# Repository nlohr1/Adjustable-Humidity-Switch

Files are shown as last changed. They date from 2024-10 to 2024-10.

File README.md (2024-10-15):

### Adjustable-Humidity-Switch

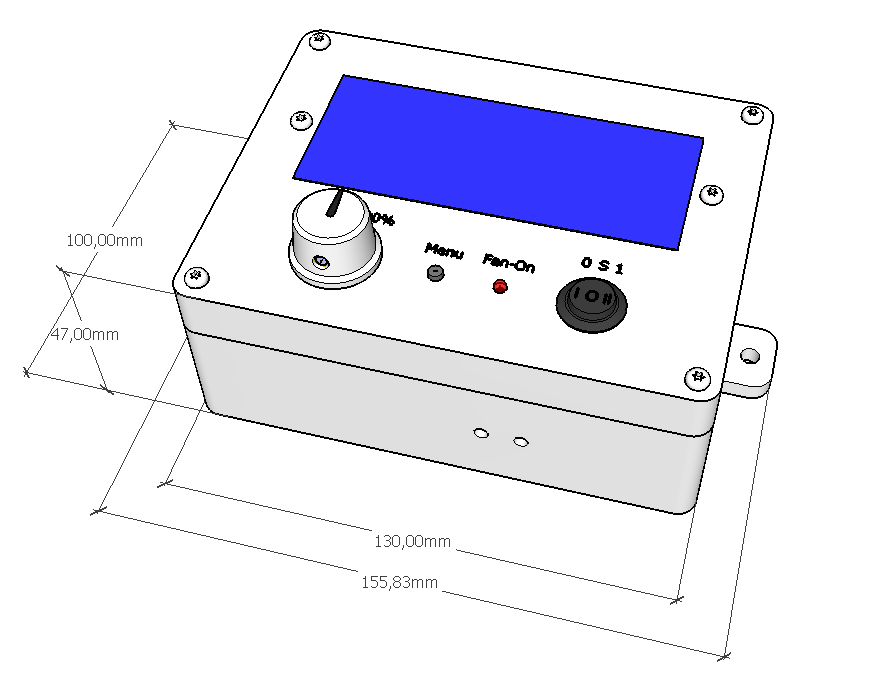
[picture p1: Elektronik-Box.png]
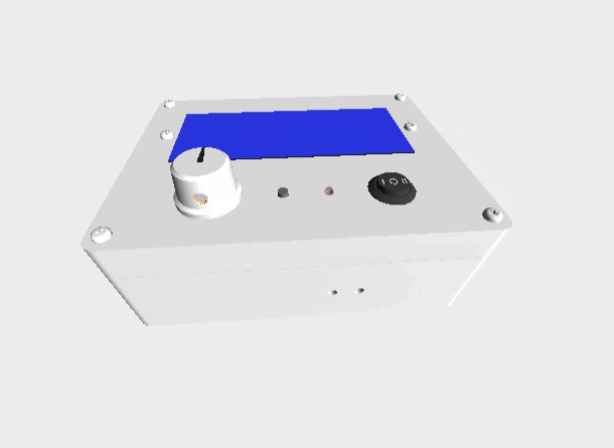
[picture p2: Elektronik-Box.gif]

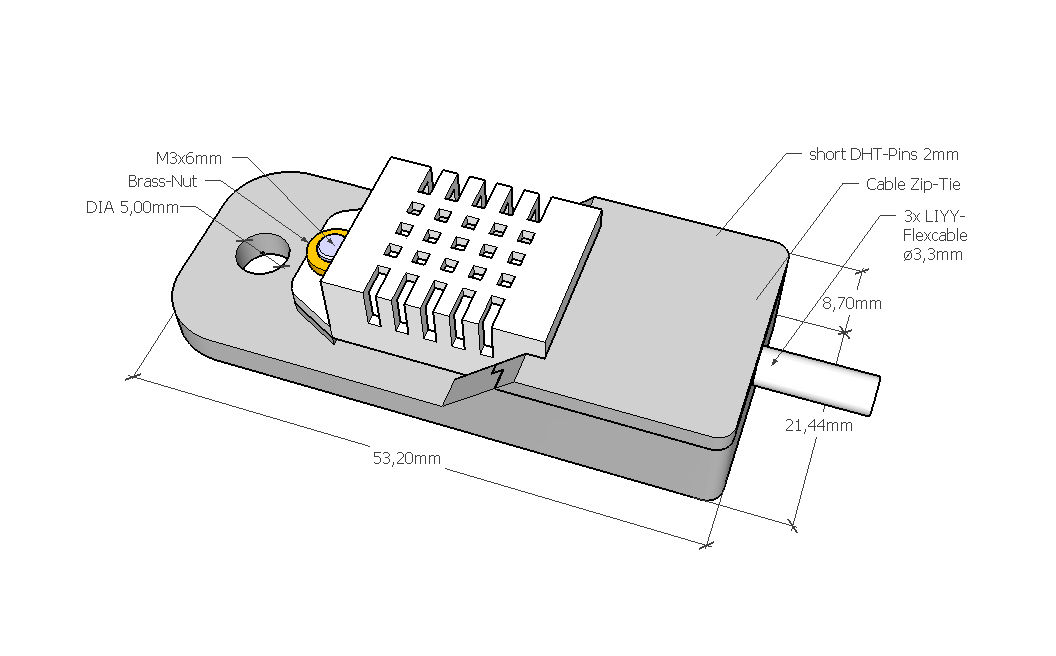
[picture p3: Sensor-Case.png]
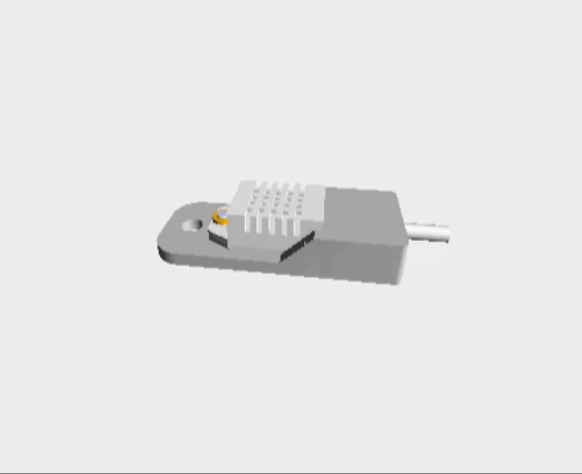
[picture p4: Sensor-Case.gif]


## EN: Adjustable Humidity-Switch
**Simple (de-)humidifier switch for all basements.**

Together with a dehumidifier or a mobile air conditioner, possibly with additional exhaust air, this is a way to keep out the poisonous "Aspergillus" (black or green mold) found in almost all basements, without using too much electricity. Unfortunately, with most dehumidifiers, the fan is always running - it cannot be switched off - and a ~800W to 3500W device can "eat up" a lot of electricity (150W continuous power for the fan?) - even if the compressor consumes most of it.  
What many people don't know or don't think about is that in many basements an invisible, radioactive gas diffuses out of the ground: radon. This gas is also odorless, so it is not noticeable, but acts like smoke - and in concentrations higher than the recommended limit (300 Bq/m³) it can attack the lungs in the long term... So if you are thinking of setting up a workspace or bedroom in the basement, you should also set up an appropriate extraction system.  
Another advantage of such an exhaust device compared to air conditioning systems or dehumidifiers: the moist, warm (+radon-containing) air is transported outside and the (indoor) air temperature remains almost the same without heating up (compressor waste heat).  
This switch works with a power relay, which can switch a consumer/device up to approx. 1400W on or off.  
The humidity threshold (the best for people is a relative humidity between 50-60%) - can be set with this switch. The dehumidifier is switched off with a small hysteresis (approx. -8% below the set value).  
I chose a capacitor type for the humidity sensor, the DHT22, because the DHT series is relatively stable and insensitive to environmental influences.  
I created and optimized the programming of the "Arduino Mini Pro" module, which handles the control and the LCD display, with the help of ChatGPT. This help makes troubleshooting in the program sequence much easier these days - so debugging is already extremely easyer.  
If you want to recreate the electronics required for this yourself, you can do it on a perforated board or recreate the board quite easily with the help of external service providers such as Eurocircuits or others. There are even (expensive) offers that take care of the assembly of the circuit board themselves. However, soldering in the few "THD" components should not be a problem for a DIY hobbyist.  

## DE: Einstellbarer Feuchte-Schalter
**Einfacher (Ent-)Feuchte Schalter für alle Keller.**

Zusammen mit einem Luftentfeuchter oder einem mobilen Klimagerät, evtl. mit zusätzlicher Abluft, ist dies eine Möglichkeit, den in fast allen Kellern anzutreffenden, giftigen "Aspergillus" (schwarzer oder grüner Schimmelbefall) fernzuhalten, ohne dabei allzu viel Strom zu verbrauchen. Bei den meisten Luftentfeuchtern läuft nämlich der Ventilator leider immer durch - nicht abschaltbar - und so ein ~800W bis 3500W Gerät kann tüchtig "Strom fressen" (150W Dauerleistung für den Lüfter?) - auch wenn der Kompressor das Meiste davon schluckt.  
Was viele zudem nicht wissen oder nicht daran denken - in vielen Kellern diffundiert ein unsichtbares, radioaktives Gas aus dem Boden: Radon. Dieses Gas ist zudem geruchlos, also nicht wahrnehmbar, wirkt aber wie Rauch - und kann in höherer Konzentration als dem empfohlenen Grenzwert (300 Bq/m³) längerfristig die Lunge angreifen... Falls man also gedenkt im Keller einen Arbeitsplatz oder ein Schlafzimmer einzurichten, sollte man dazu auch gleich eine entsprechende Absauganlage einrichten.  
Ein weiterer Vorteil eines solchen Abluft-Gerätes gegenüber Klimaanlagen oder Entfeuchtern: die feuchte, warme (+radonhaltige) Luft wird nach draußen befördert und die (Innen-)Lufttemperatur bleibt annähernd gleich, ohne sich zu erhitzen (Kompressor-Abwärme).  
Dieser Schalter arbeitet mit einem Power-Relais zusammen, welches einen Verbraucher/Gerät bis zu ca. 1400W ein- bzw. ausschalten kann.  
Die Feuchtigkeits-Schwelle (am besten für Menschen ist eine relative Luftfeuchtigkeit zwischen 50-60%) - ist bei diesem Schalter einstellbar. Mit einer kleinen Hysterese (ca. -8% unter dem eingestellten Wert) wird der Entfeuchter ausgestellt.  
Als Feuchtesensor habe ich einen Kondensator-Typ gewählt, den DHT22, da die DHT-Serie gegen Umwelteinflüsse relativ stabil und unempfindlich ist.  
Die Programmierung des "Arduino-Mini-Pro" Moduls, welches die Steuerung und die LCD-Anzeige übernimmt, habe ich mit Hilfe von ChatGPT erstellt und optimiert. Diese Hilfe vereinfacht heutzutage die Fehlersuche im Programmablauf - das "debugging" schon extrem.  
Wer die dazu erforderliche Elektronik selbst nachbauen will, kann diese auf einer Lochrasterplatine oder das Board mit Hilfe von externen Dienstleistern wie Eurocircuits o.a. auf recht einfache Weise nachbauen. Es gibt dazu sogar (teure) Angebote, die selbst die Bestückung der Leiterplatte übernhemen. Die wenigen "THD"-Bauteile einzulöten sollte aber kein Problem für einen DIY-Bastler sein.

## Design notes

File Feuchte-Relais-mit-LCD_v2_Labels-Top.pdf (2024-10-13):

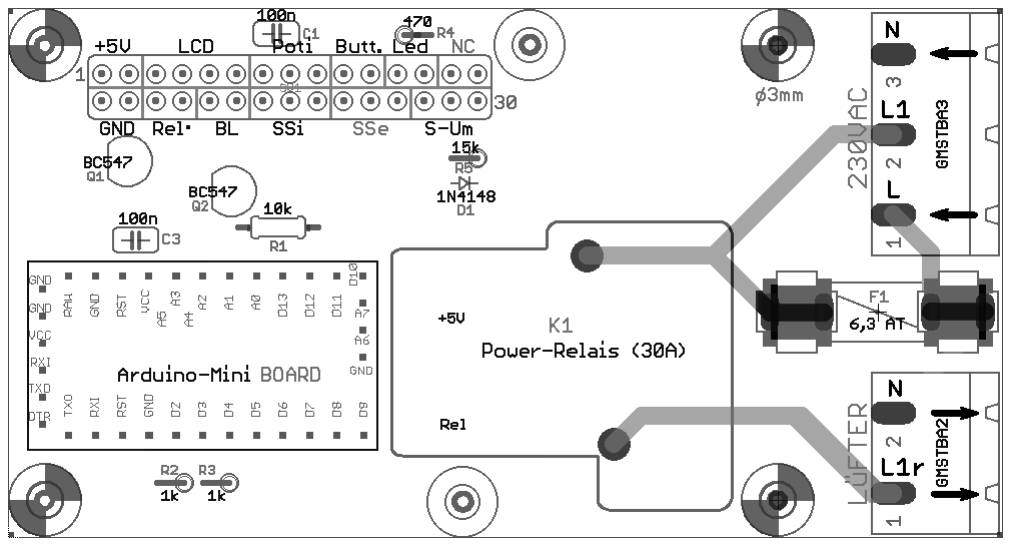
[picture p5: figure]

Feuchte-Relais-mit-RTC-&-LCD Top-Labels

Board: 94 x 50 mm

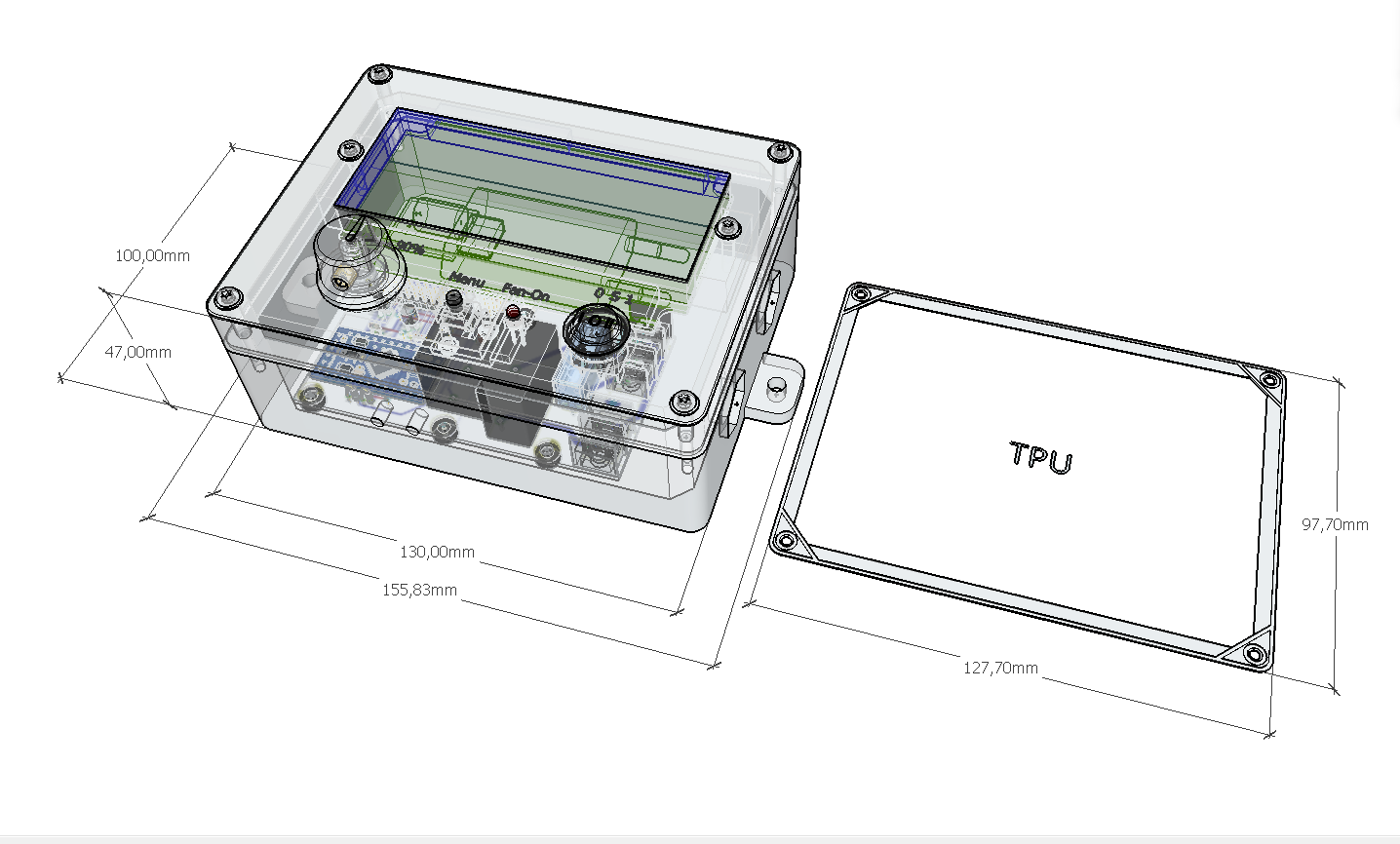
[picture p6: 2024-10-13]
Elektronik-Box-.png

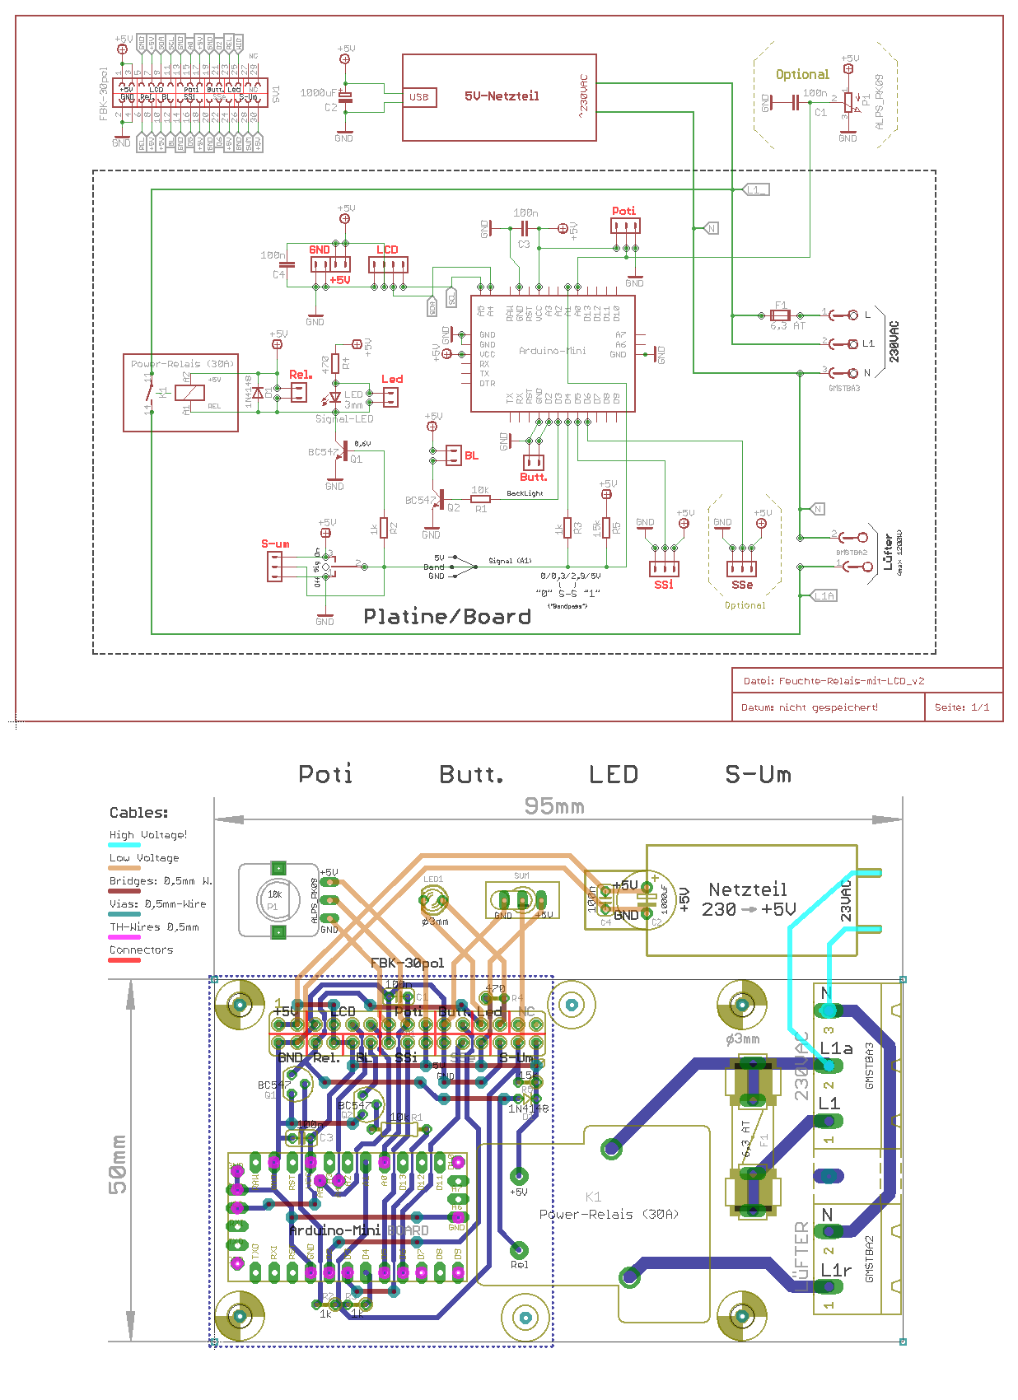
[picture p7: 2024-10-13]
Feuchte-Relais-mit-LCD_v2.png

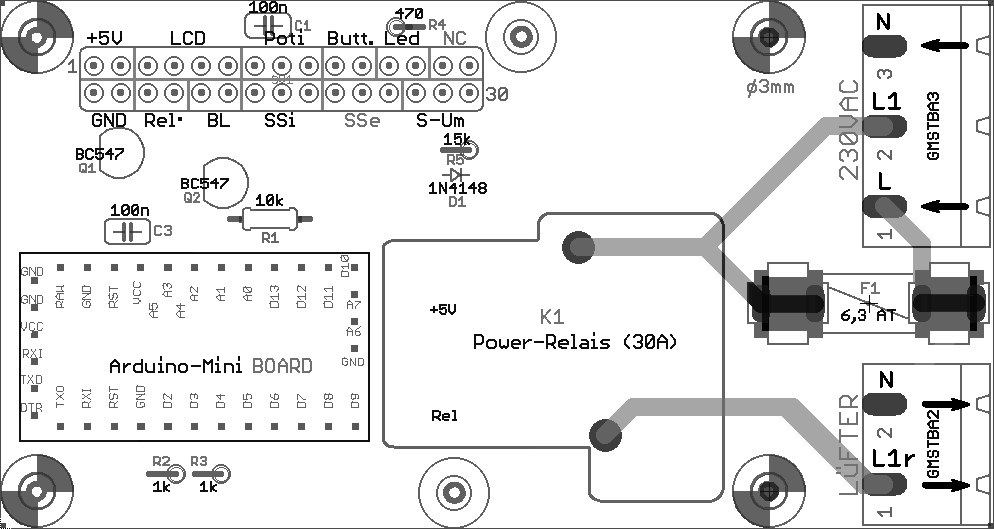
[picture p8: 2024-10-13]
Feuchte-Relais-mit-LCD_v2_Labels-Top.png

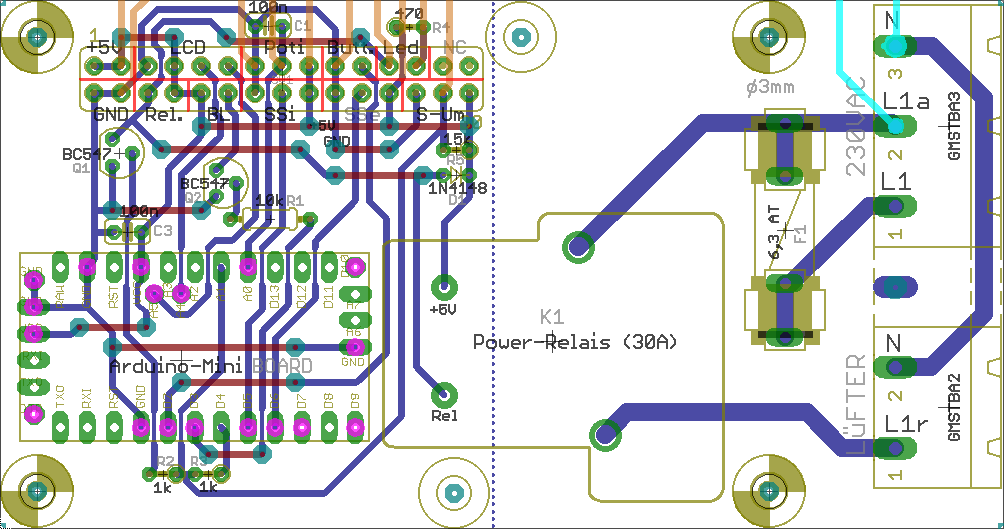
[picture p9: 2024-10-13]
Board_2D_Feuchte-Relais-mit-RTC-&-LCD.png

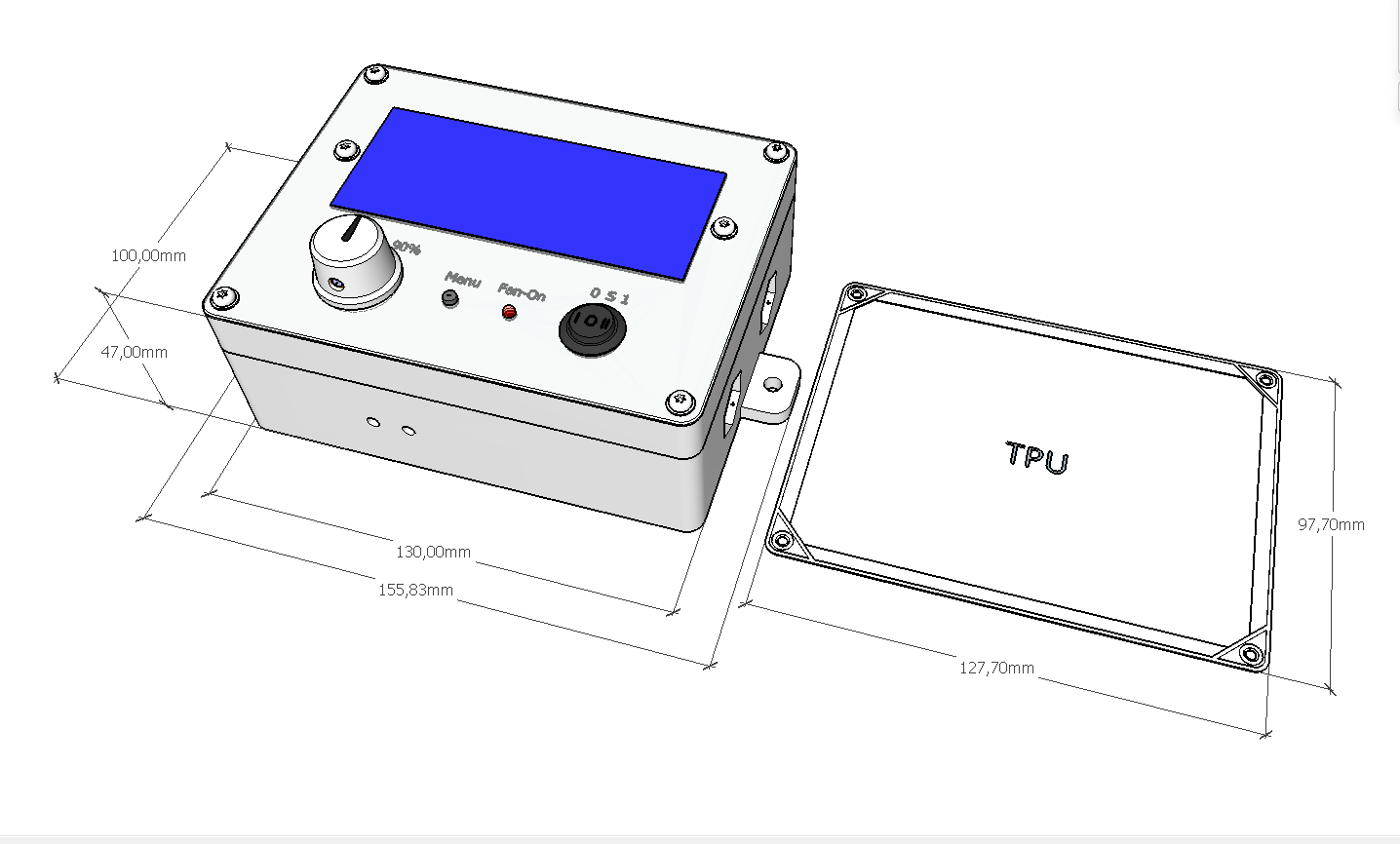
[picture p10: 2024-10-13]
Elektronik-Box+.png

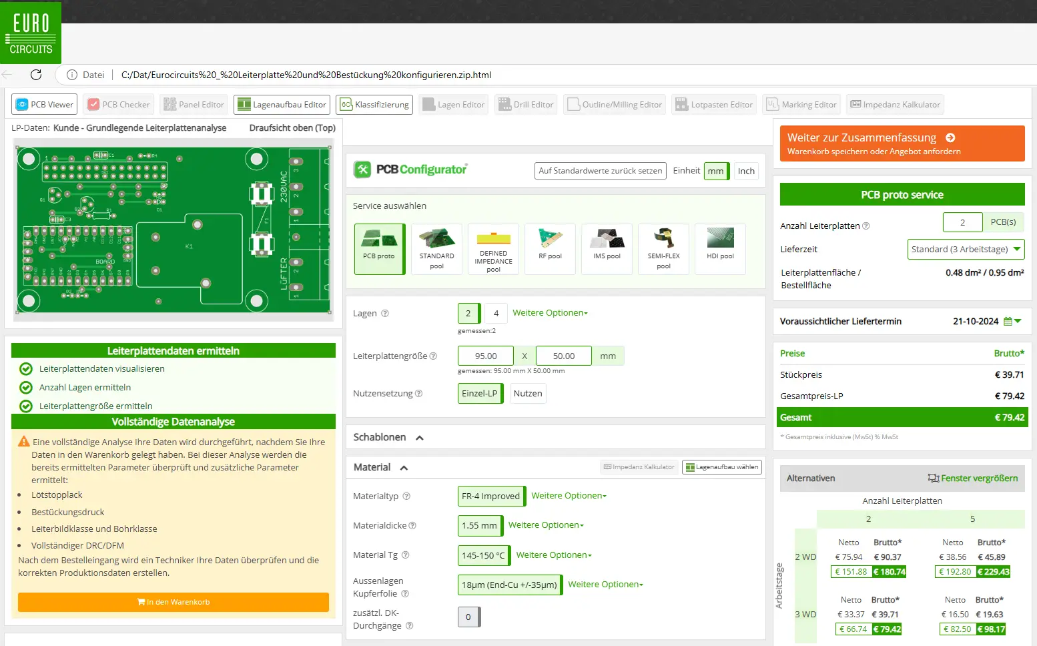
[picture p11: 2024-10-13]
Eurocircuits_Leiterplatten-Konfiguration_2x40,00 €.webp

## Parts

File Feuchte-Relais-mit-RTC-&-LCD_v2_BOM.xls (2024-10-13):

Manufacturer Part Number | Description | Reference Designator | Quantity | Manufacturer | Supplier Part Number | Supplier name | Package name | Mounting type | Comment | URL | URL-2
KF128 PCB Mount Terminal 7,5mm Pitch 3 Pin | PCB Screw Terminal, green, 6-Pin (3x2Pin) 7,62mm Pitch | 230VAC | 1 | --- | --- | --- | PCB board Connector | THD | (3Pin x2) | https://de.aliexpress.com/item/1005001677842589.html
Arduino-Mini-Pro, 5V | Arduino-Mini-Pro, 5V Module | BOARD | 1 | --- | --- | --- | ARDU-MINI | THD | Module | https://www.az-delivery.de/products/pro-mini-100-arduino-kompatibel
0.1uF 100V X7R Ceramic Capacitor, Radial, 2.54mm | Ceramic Capacitor, THD (2,54mm Pitch) | C1, C3, C4 | 3 | --- | --- | --- | C025-024 | THD | 100nF | https://de.aliexpress.com/item/1005005934204177.html | https://www.reichelt.de/vielschicht-kerko-100-nf-100-v-x7r-10-rm-2-5-ammo-x7r-2-5-100n-kom-p329838.html
470uF 60V Polarized Capacitor, Radial | Polarized Capacitor, THD (7,62mm Pitch) | C2 | 1 | --- | --- | --- | E3,5-8 | THD | 1000uF | https://www.reichelt.de/elko-radial-470-uf-35-v-105-c-low-esr-fm-a-470u-35-p200054.html
1N4148 | Generic Diode 100mA, THD (2,54mm Pitch) | D1 | 1 | --- | --- | --- | D-2.5 | THD | 1N4148 | https://www.reichelt.de/schalt-diode-100-v-150-ma-do-35-1n-4148-p1730.html
Fuse-Holder 6,3 AT | Fuse 5x20mm (for 1300W-Fan max.), THD | F1 | 1 | --- | --- | --- | FUSE | THD | Ø5xL:20mm | https://www.reichelt.de/feinsicherung-5x20mm-traege-6-3a-tr-6-3a-p21800.html | https://www.reichelt.de/sicherungshalter-fuer-5x20mm-6-3x32mm-pl-ogd-p53019.html
Power Relay 30A | Power Relay 230V, 30A, 5V (Schrack / Songle) | K1 | 1 | --- | --- | --- | ZD2 | THD | („Songle“-Relais) | https://de.aliexpress.com/item/1005006195915573.html | https://ampul.eu/de/relais-magnetische-kontakte/4824-relais-sla-05vdc-sl-c-5v-dc-250v-ac-30a
LED 3mm | LED diffuse red, THD | LED1 | 1 | --- | --- | --- | LED3MM | THD | 150mcd | https://www.reichelt.de/led-3mm-bedrahtet-rot-150-mcd-60--3004r1d-ehb-a-p361902.html
ALPS Rotary Potentiometer "RK09 Series" | Rotary Potentiometer | P1 | 1 | --- | --- | --- | RK09 | THD | 10k | https://in.rsdelivers.com/product/alps-alpine/rk097111030x/alps-alpine-10k%CF%89-rotary-carbon-film-potentiometer/2499121
Generic NPN-Transistor | BC547 NPN-Transistor | Q1, Q2 | 2 | --- | --- | --- | SOT54A | THD | (TO92) | https://www.ebay.de/itm/181079029042
Carbon Film Resistor (Yageo) | Resistor 0.25W, 5%, THD | R1 | 1 | --- | --- | --- | 0207 | THD | 10kΩ | https://www.reichelt.de/widerstand-kohleschicht-10-kohm-0207-250-mw-5--1-4w-10k-p1338.html
Carbon Film Resistor (Yageo) | Resistor 0.25W, 5%, THD | R2, R3 | 2 | --- | --- | --- | 0207 | THD | 1kΩ | https://www.reichelt.de/widerstand-kohleschicht-1-0-kohm-0207-250-mw-5--1-4w-1-0k-p1315.html
Carbon Film Resistor (Yageo) | Resistor 0.25W, 5%, THD | R4 | 1 | --- | --- | --- | 0207 | THD | 470 Ω | https://www.reichelt.de/widerstand-kohleschicht-470-ohm-0207-250-mw-5--1-4w-470-p1432.html
Carbon Film Resistor (Yageo) | Resistor 0.25W, 5%, THD | R5 | 1 | --- | --- | --- | 0207 | THD | 15kΩ | https://www.reichelt.de/widerstand-kohleschicht-15-kohm-0207-250-mw-5--1-4w-15k-p1356.html
Tiny Switch Rocker Black Round ON/OFF/ON 3 Pin | Switch On/Off/On | SUM | 1 | --- | --- | --- | TL3XPO | THD | On/Off/on | https://www.ebay.de/itm/184249111151
Dual Pin-Header 2.54mm, THD | Dual Pin-Header gold-plated 2.54mm, THD | SV1 | 1 | --- | --- | --- | MA15-2 | THD | Header / Crimp-Conn. | https://www.amazon.de/gp/product/B09NKXY4C4 | https://de.aliexpress.com/item/1005005670566115.html, https://www.ebay.de/itm/170938740983

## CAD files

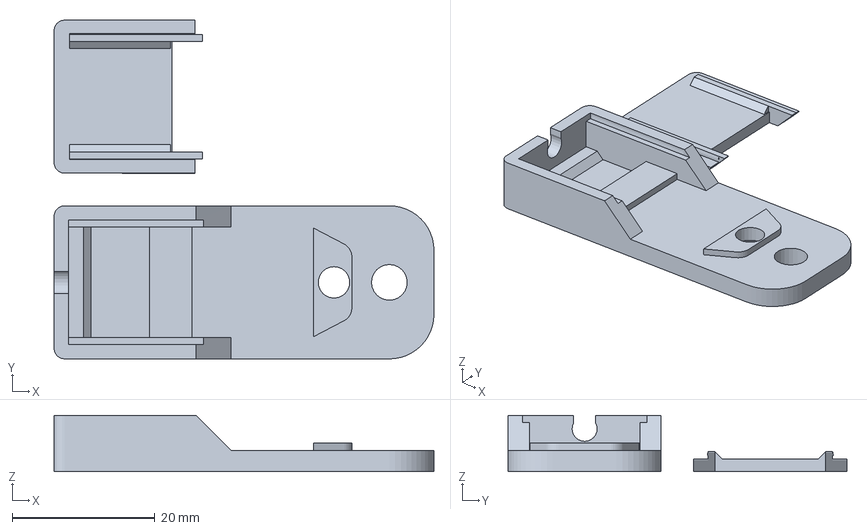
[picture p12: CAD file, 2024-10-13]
Sensor-Case/H-Sensor-Wallmount-Case.3mf
53.2 x 47.4 x 7.90 mm

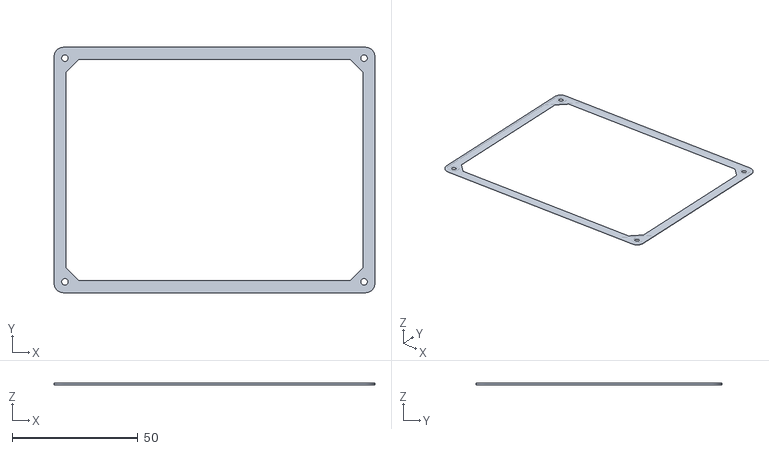
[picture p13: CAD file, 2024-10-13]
STL-Parts/Elektronik-Box_TPU_Seal.stl
127.7 x 97.7 x 0.6

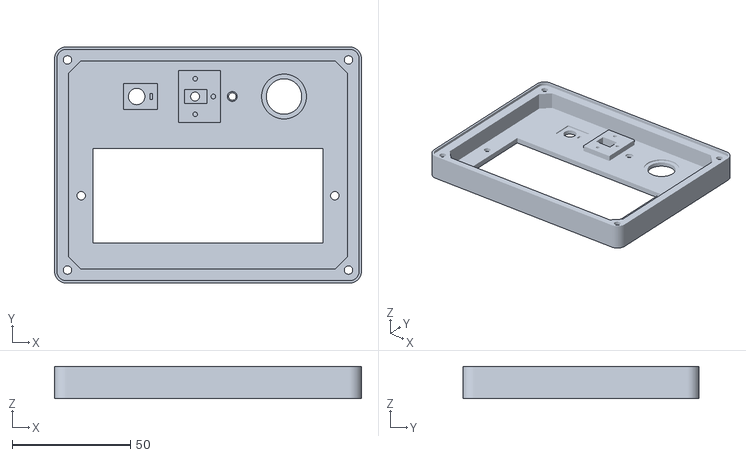
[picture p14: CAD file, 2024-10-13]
STL-Parts/Elektronik-Box_top.stl
130.0 x 100.0 x 13.6

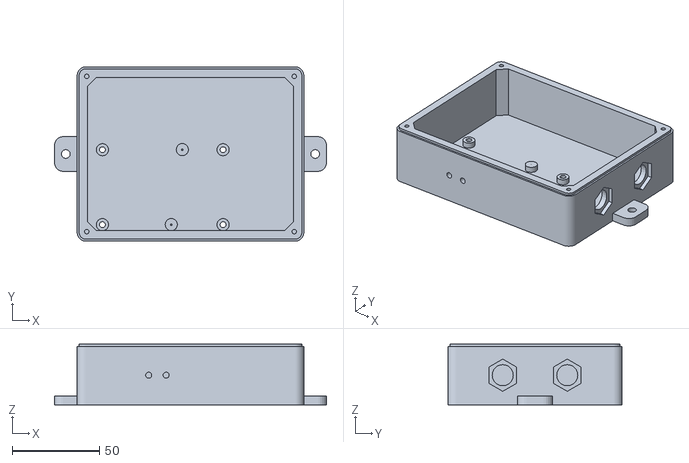
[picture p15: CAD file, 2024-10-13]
STL-Parts/Elektronik-Box_base_w-holes.stl
156.0 x 100.0 x 34.8

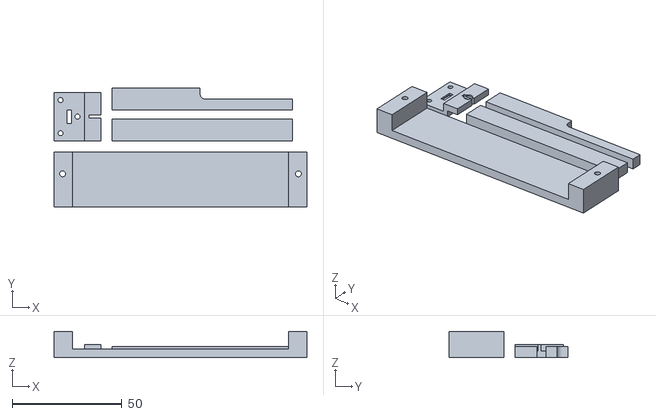
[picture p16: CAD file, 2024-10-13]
STL-Parts/LCD-Spacer_82x10x5mm.stl
115.2 x 54.0 x 12.0

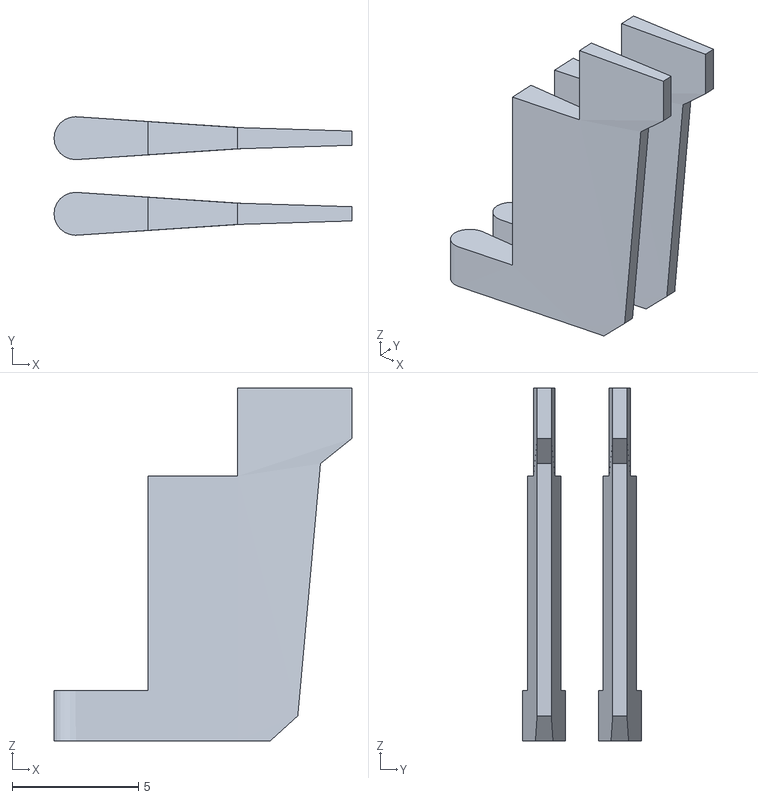
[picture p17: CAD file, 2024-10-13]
STL-Parts/Knob-Pointer_black.stl
11.8 x 4.70 x 14.0

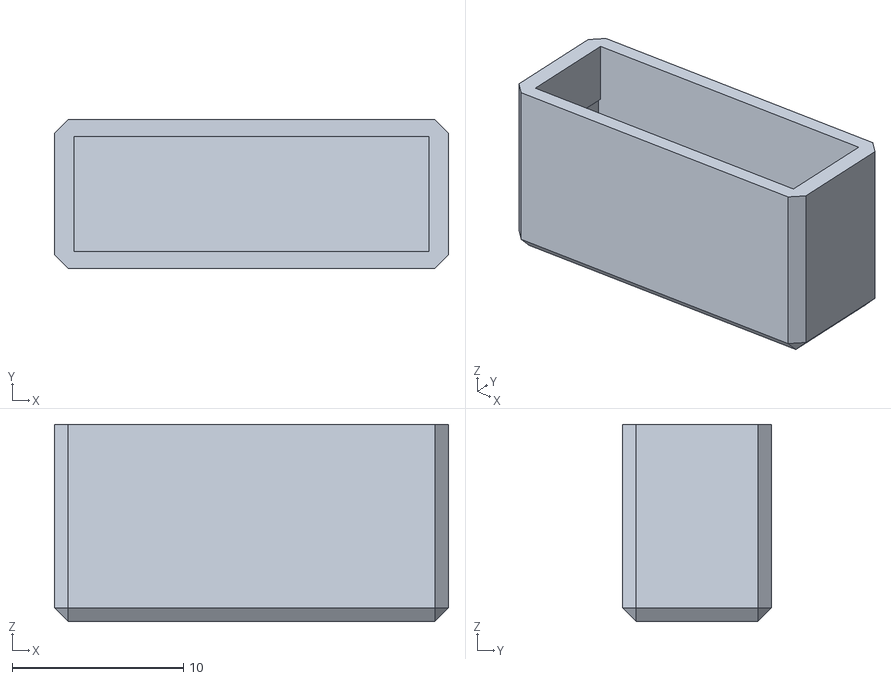
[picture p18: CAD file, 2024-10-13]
STL-Parts/Fuse cover.stl
23.0 x 8.70 x 11.5

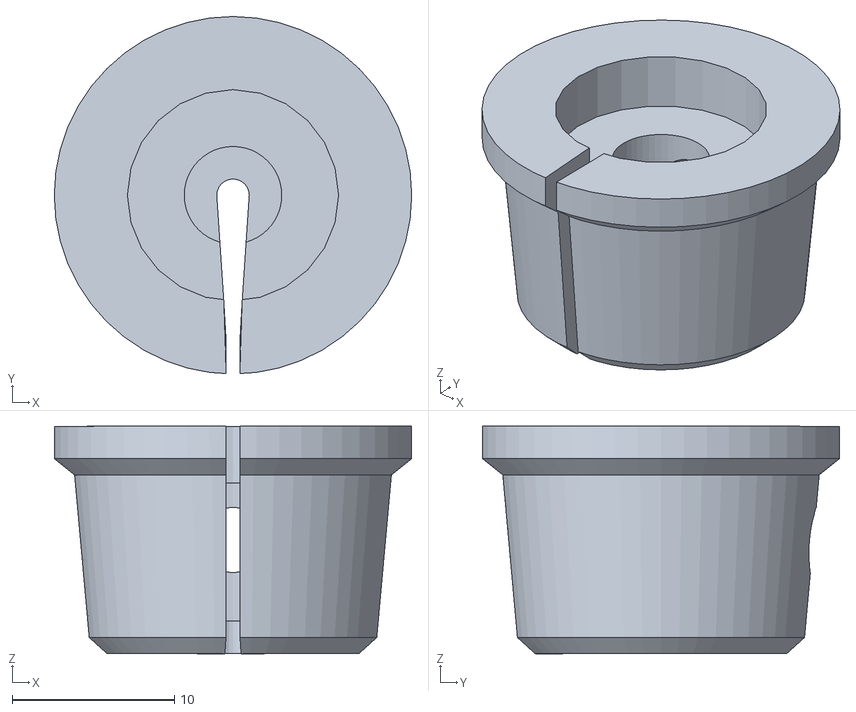
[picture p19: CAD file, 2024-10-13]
STL-Parts/Knob-white.stl
22.0 x 22.0 x 14.0

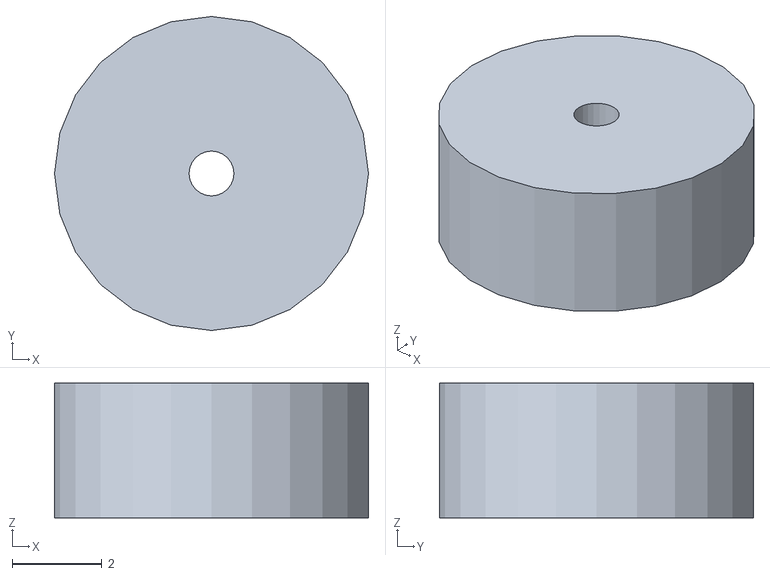
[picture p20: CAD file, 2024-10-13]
STL-Parts/Board-Spacer).stl
7.00 x 7.00 x 3.00

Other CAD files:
STL-Parts/Elektronik-Box_base_w-inserts.stl
Board-3D_Feuchte-Relais-mit-RTC-&-LCD.skp
Sensor-Case/H-Sensor-Wallmount-Case.skp
Sensor-Case/H-Sensor-Wallmount-Case.stl
Sensor-Case/Thread-Insert_M3-Brass.skp

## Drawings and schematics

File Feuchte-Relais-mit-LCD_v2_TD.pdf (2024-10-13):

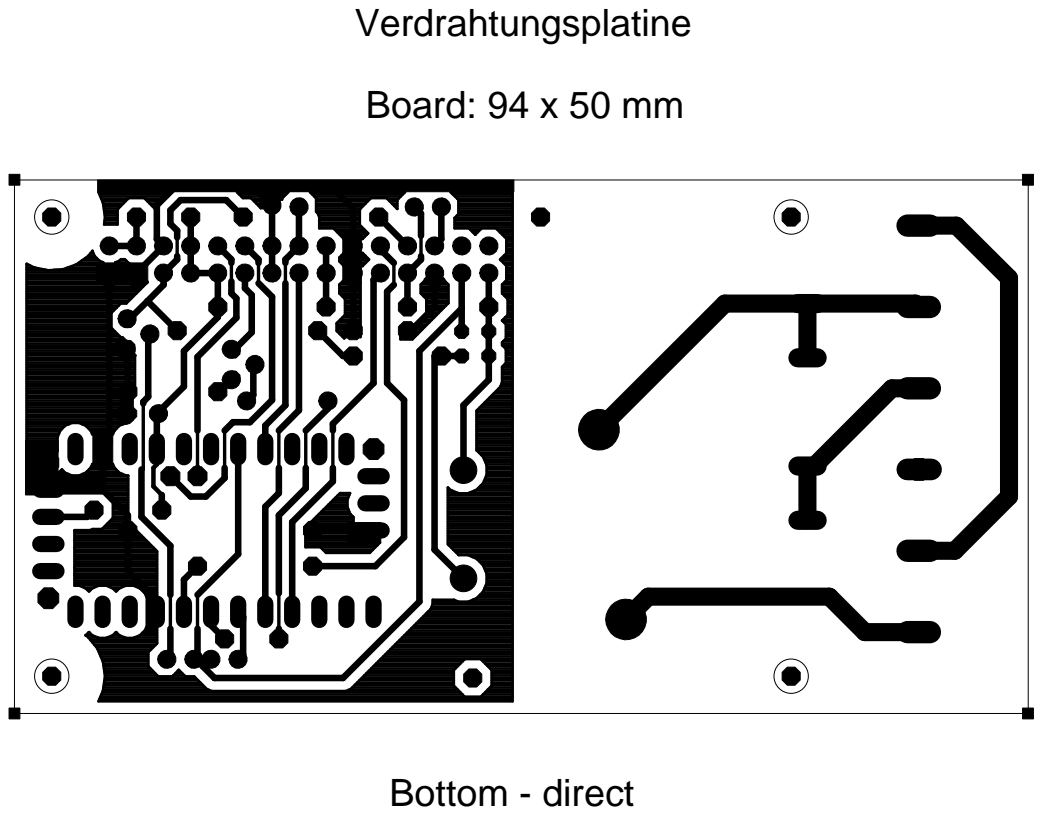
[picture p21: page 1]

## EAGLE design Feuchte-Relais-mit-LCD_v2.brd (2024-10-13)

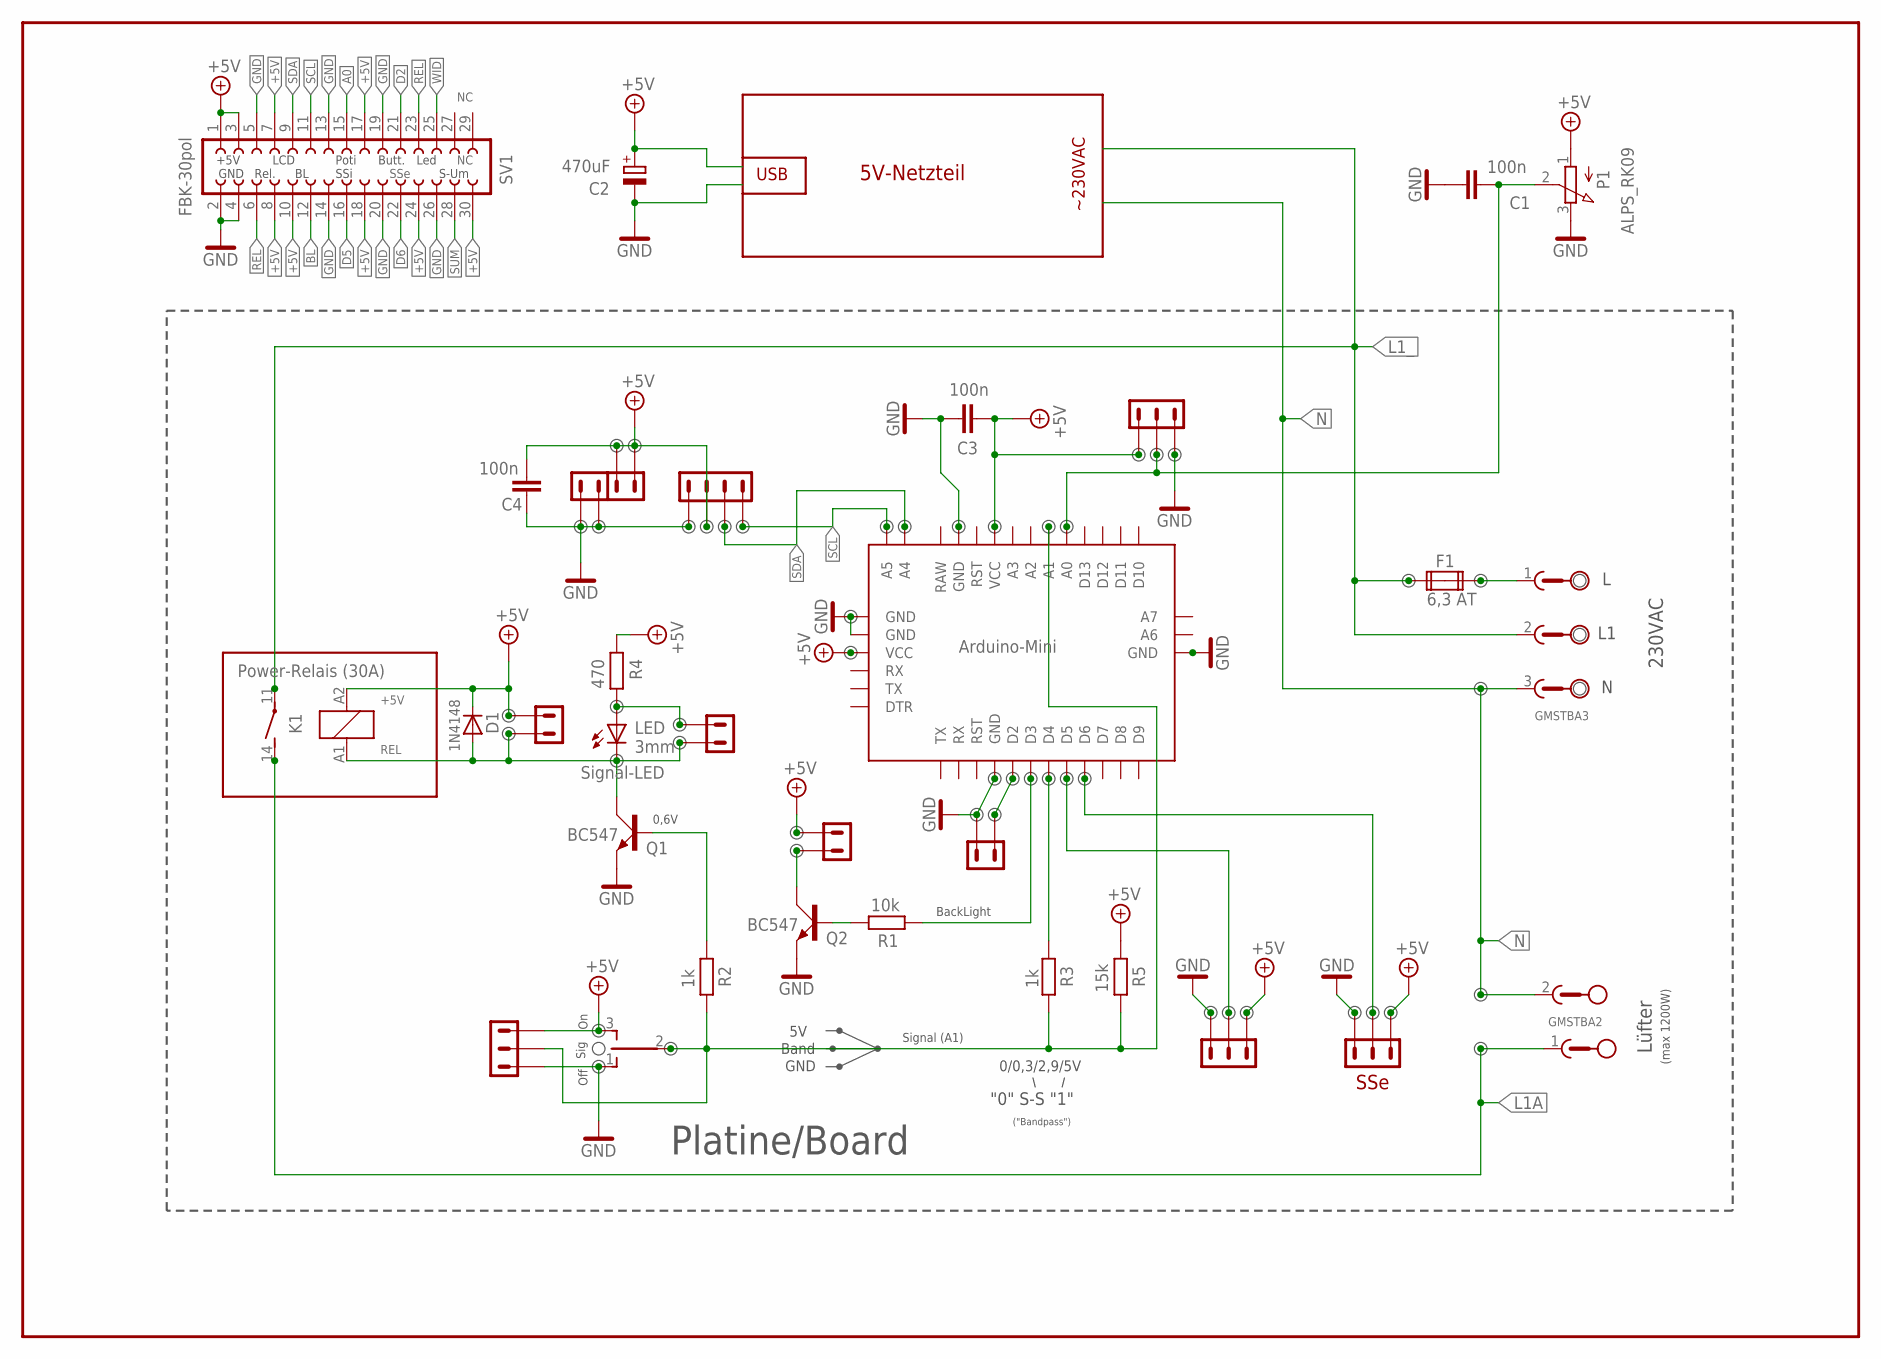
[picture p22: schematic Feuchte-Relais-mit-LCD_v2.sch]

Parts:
230VAC: GMSTBA3
BOARD: Arduino-Mini; ARDU-MINI
C1, C3, C4: 100n; C025-024X044
C2: 470uF; E3,5-8
D1: 1N4148; D-2.5
F1: 6,3 AT; FUSE1
K1: Power-Relais (30A); ZD2
LED1: o3mm; LED3MM
LüFTER: GMSTBA2
P1: ALPS_RK09; RK09
Q1, Q2: BC547; SOT54A
R1: 10k; 0204/7
R2, R3: 1k; 0204V
R4: 470; 0204V
R5: 15k; 0204V
SUM: TL39PO; TL3XPO
SV1: FBK-30pol; FE15-2

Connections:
+5V: BOARD.P$21 (VCC), BOARD.P$27 (VCC), C2.+, C3.1, C4.2, D1.C, K1.A2 (2), P1.1 (A), R4.1, R5.1, SUM.3 (S), SV1.1, SV1.3, SV1.7, SV1.8, SV1.10, SV1.17, SV1.18, SV1.24, SV1.30
A0: BOARD.P$17 (A0), C1.2, P1.2 (S), SV1.15
A1: BOARD.P$18 (A1), R2.1, R3.2, R5.2, SUM.2
BL: Q2.C, SV1.12
D2: BOARD.P$5 (D2), SV1.21
D3: BOARD.P$6 (D3), R1.1
D4: BOARD.P$7 (D4), R3.1
D5: BOARD.P$8 (D5), SV1.16
D6: BOARD.P$9 (D6), SV1.22
GND: BOARD.P$4 (GND), BOARD.P$23 (GND), BOARD.P$25 (GND), BOARD.P$26 (GND), BOARD.P$31 (GND), C1.1, C2.-, C3.2, C4.1, P1.3 (E), Q1.E, Q2.E, SUM.1 (O), SV1.2, SV1.4, SV1.5, SV1.13, SV1.14, SV1.19, SV1.20, SV1.26
L: 230VAC.1, F1.2A
L1A: K1.14 (S), LüFTER.1
L1_: 230VAC.2, F1.1A, K1.11
N: 230VAC.3, LüFTER.2
unnamed: Q1.B, R2.2
unnamed: Q2.B, R1.2
REL: D1.A, K1.A1 (1), LED1.K (C), Q1.C, SV1.6, SV1.23
SCL: BOARD.P$35 (A5), SV1.11
SDA: BOARD.P$34 (A4), SV1.9
SUM: SV1.28
WID: LED1.A, R4.2, SV1.25

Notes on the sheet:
USB
~230VAC
5V-Netzteil
Lüfter
Platine/Board
Off
Sig
Signal (A1)
230VAC
LED 3mm
BackLight
REL
+5V
(max 1200W)
Signal-LED
0/0,3/2,9/5V
"0" S-S "1"
("Bandpass")
0,6V
5V Band GND
GND
Rel.
LCD
S-Um
Butt.
Led
SSi
SSe
Poti

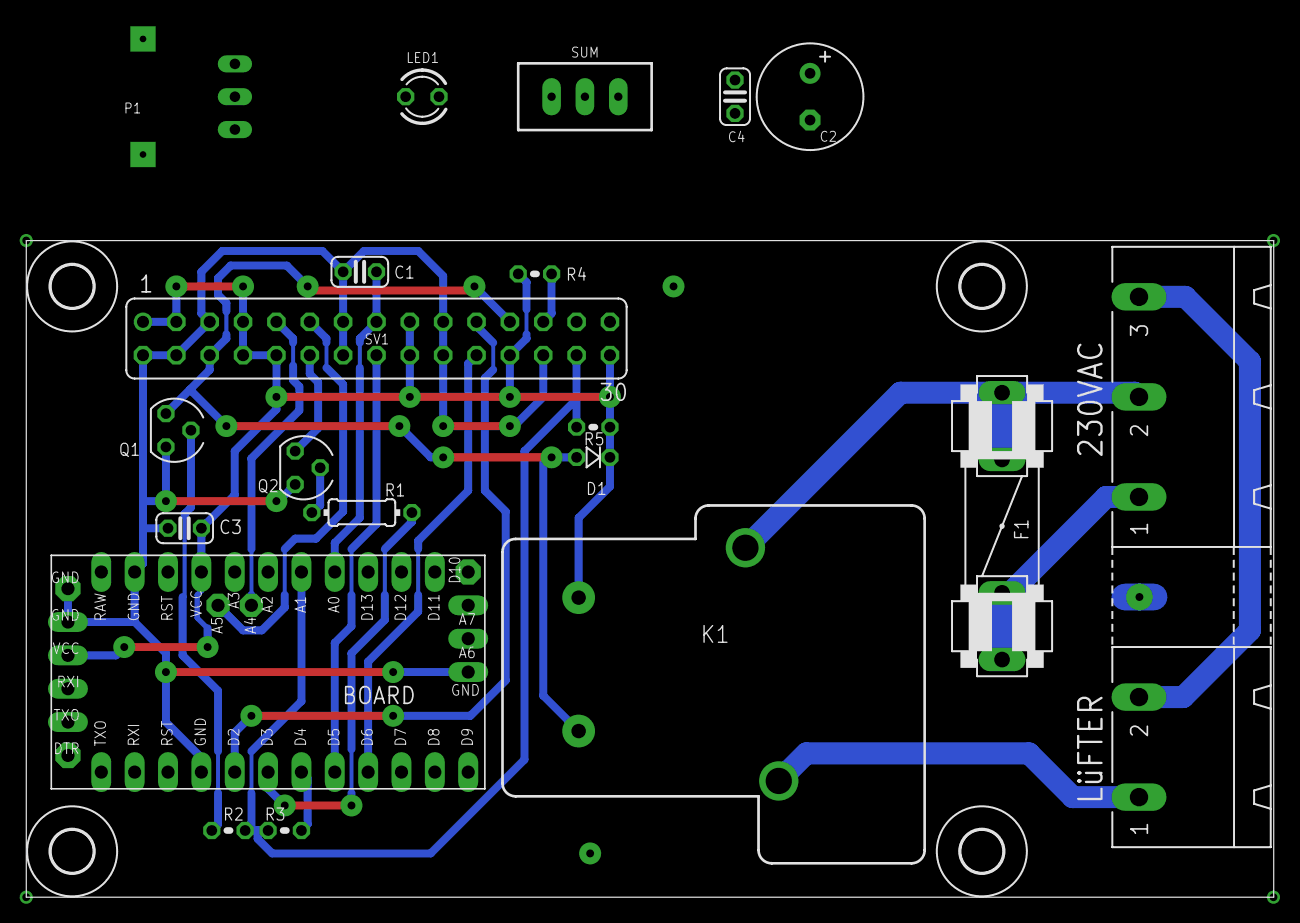
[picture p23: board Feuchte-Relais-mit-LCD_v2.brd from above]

Board: 2 copper layers, 95.0 x 50.0 mm, 25 parts (1 on the bottom side), 20 nets.

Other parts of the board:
U$1, U$2, U$3, U$4: 3,2

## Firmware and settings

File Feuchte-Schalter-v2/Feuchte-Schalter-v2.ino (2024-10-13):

//********************************************************************************
//Humidity-Relais with LCD-Display (20x4)
//********************************************************************************
//... (alle Kommentare und die ursprünglichen Komponentenbeschreibung) ...

//Libraries used:
#include "DHT.h"                 //https://github.com/adafruit/DHT-sensor-library
#include <SPI.h>                 //	(Arduino-internal) ../Arduino/hardware/arduino/avr/libraries/SPI
#include <Wire.h>                //(Arduino-internal) ../Arduino/libraries/Wire
#include <LiquidCrystal_I2C.h>   //https://github.com/fdebrabander/Arduino-LiquidCrystal-I2C-library

//Pin-Connections:
//Pin-Name          Pin //Explanation
#define potiPin     A0  //Input for the 10k-Poti
#define switchPin   A1  //Input for the 3-state Switch (0V | bandpass | 5V)
#define MenuPin     2   //Input for the Menu-Button (Att.: With internal PullUp-Resistor activated, see Setup)
#define pwmPinForBL 3   //PWM Output to turn-On the Backlight-Transistor (dimming with 2s transition)
#define RelaisPin   4   //Output Pin for the Relay Transistor
#define DHTPin_a    5   //Sensor_a Input (default configuration!)
#define DHTPin_b    6   //Sensor_b Input (only if 2nd. Dew Point Sensor present for automatic difference-calculation)

#define DHTType DHT22
DHT dht(DHTPin_a, DHTType);

//-------------------------- Variables ---------------------------
bool relais = false;            //Relay status
int potiValue = 0;              //Potentiometer value
int potiValueOld = 0;           //Previous potentiometer value
volatile bool BUTTON_2 = true;  //Button status for D2
float temperature;                     //Measured temperature
float humidity;                 //Measured humidity
unsigned long previous;         //Timestamp for display refresh
int hysterese = 6;              //Hysteresis for relay control
char tempStr[6];                //String buffer for temperature
char humidityStr[6];            //String buffer for humidity

bool backlightOn = false;       //Backlight status (if dimmed or full brightness)
unsigned long backlightPrevious = 0;   //Timestamp for backlight control
unsigned int backlightTimeout = 60000; //60 seconds timeout for backlight, then 1s dimming to 10% intensity
unsigned int displayRefreshInterval = 1500; //1.5 seconds interval = display refresh time
bool isDimming = false;         //Define a flag to prevent double dimming while dimming

LiquidCrystal_I2C lcd(0x27, 20, 4); //LCD: Address 0x27, 20 characters, 4 lines


//~~~~~~~~~~~~~~~~~~~~~~~~~~ Setup ~~~~~~~~~~~~~~~~~~~~~~~~~~
void setup() {
  Serial.begin(9600);
  dht.begin();  //initialize Humidity-Sensor

//Att.: On begin all Pins are Input-Pins, so no need to declare Input-Pins here twice - if used as Input...
  pinMode(RelaisPin, OUTPUT);
  pinMode(MenuPin, INPUT_PULLUP);  //Pullup activated for MenuPin (D2)

  attachInterrupt(digitalPinToInterrupt(MenuPin), ButtonD2_LOW, FALLING); 

  lcd.begin();        //initialize LCD-Display
  lcd.backlight();    //Backlight "On"
  dimBacklight(true); //Start with full backlight (100%), see dim-function @ the end

  byte Grad[8] = {B00111, B00101, B00111, B0000, B00000, B00000, B00000, B00000}; //Create custom character "°" as array
  lcd.createChar(0, Grad); //Create special character °, to display temperature in Centigrade on the LCD

}

//~~~~~~~~~~~~~~~~~~~~~~~~~~ Main-Loop ~~~~~~~~~~~~~~~~~~~~~~~~~~
void loop() {
  temperature = dht.readTemperature();
  humidity = dht.readHumidity();

  //Detection, if the Sensor sends a valid Signal:
  if (isnan(temperature) || isnan(humidity)) {
    lcd.clear();
    lcd.setCursor(0, 0);
    lcd.print("Sensor Error!");
    lcd.setCursor(0, 1);
    lcd.print("No values.");
    delay(2000);
    return;
  }

  //ReadOut of Poti-position:
  potiValue = analogRead(potiPin); //readout actual Poti-position
  potiValue = map(potiValue, 0, 1023, 20, 100); //calculate the spread (target is from 0-255)
  if (potiValue <= 30) { potiValue = 30; } //don't decrease below 30%
  if (potiValue >= 90) { potiValue = 90; } //don't increase above 90%

  //Activate the Relay if RH is just above potiValue - and deactivate if 8% below
  if (humidity >= potiValue) {
    digitalWrite(RelaisPin, HIGH);
    relais = true; //turn on the Relay
  } else if (humidity < potiValue - hysterese) {
    digitalWrite(RelaisPin, LOW);
    relais = false; //turn off the Relay
  }

  //if either the Poti or the MenuButton was touched...
  if ((BUTTON_2 == LOW || potiValue != potiValueOld) && !isDimming) { //"isDimming" = ensure only one dimming event
    dimBacklight(true); //...then set the backlight to 100% brightness
    backlightOn = true;
    backlightPrevious = millis(); //set value to actual millis()
    BUTTON_2 = HIGH;              //reset the flag
    potiValueOld = potiValue;
    isDimming = true;             // Set dimming flag to true
  }

  //TimeOut after 60 seconds:
  if (backlightOn && millis() - backlightPrevious >= backlightTimeout) {
    dimBacklight(false); //dim backlight to 10% brightness
    backlightOn = false;
    isDimming = false;            // Reset dimming flag after timeout
  }

  //Dimming-Timeout:
  if (millis() - previous >= displayRefreshInterval) { //1500ms
    previous = millis();

    dtostrf(temperature, 2, 0, tempStr);
    dtostrf(humidity, 2, 0, humidityStr);

    lcd.clear();              
    lcd.setCursor(0, 0);
    lcd.print("Temp.:   ");
    lcd.print(tempStr);
    lcd.write((uint8_t)0);  //° symbol
    lcd.print("C");

    lcd.setCursor(0, 1);      
    lcd.print("Feuchte: ");
    lcd.print(humidityStr);
    lcd.print(" %");

    lcd.setCursor(0, 2);      
    lcd.print("Poti:    ");
    lcd.print(potiValue);
    lcd.print(" %");

    lcd.setCursor(0, 3);      
    lcd.print("Trockner ");
    lcd.print(relais ? "EIN" : "AUS");
  }

  //Read analog value from Pin-A1 Input for switch status and display the result on LCD-Display (right side of the last line):
  int analogValue = analogRead(switchPin); //read-out the Switch-Position on Pin-A1 (input)
  lcd.setCursor(17, 3); //Move to the right side of the last line, position 17 (of 20)
    
  if (analogValue > 900) {
    lcd.print("__1"); //Permanent-On (Switch on +5V)
  }
  else if (analogValue > 60 && analogValue <= 900) {
    lcd.print("_S_"); //Sensor mode (Switch on "S" position ⇒ detect if within "bandpass" between 2.9V and 0.3V through analog-Pin A1)
  }
  else {
    lcd.print("0__"); //Permanent-Off (Switch on 0V)
  }

} //~~~~~~~~~~~~~~~~~~~~~~~~~~ End of Main-Loop ~~~~~~~~~~~~~~~~~~~~~~~~~~


//-------------------------- Functions --------------------------
void ButtonD2_LOW() {
  BUTTON_2 = LOW; //Set button flag to LOW if Button pressed (to GND)
}

//Function to dim the backlight from 10% to 100% and viceversa
void dimBacklight(bool turnOn) { //"turnOn" flag is set either "1" or "0"
  int delayTime = 10;  //milliSeconds (for PWM-pause ¯¯\_/¯¯ )
  int stepCount = 100; //counts (100 steps of 10ms = 1s total transition-time)
  int start = turnOn ? 25 : 255; //dim-UP  from 10% to 100% - if "turnOn" is TRUE = "1"
  int end = turnOn ? 255 : 25;   //dim-DOWN from 100% to 10% if "turnOn" is FALSE = "0"
  int step = (end - start) / stepCount; //step-"width" calculation

  for (int brightness = start; (turnOn ? brightness <= end : brightness >= end); brightness += step) {
    analogWrite(pwmPinForBL, brightness); //"brightness" is the changing value (from 25 to 255)
    delay(delayTime);
  }
}

/* Display Example:
-------------------
Temp:    25°C
Feuchte: 75 %
Poti:    60 %        Relay: directly "On" above 60% and "Off" below 52% RH (52 = 60%-8% hysteresis)
Trockner EIN        (EIN | AUS)
-------------------------------

Explanation:
************
Button and Potentiometer:
Button and Potentiometer activate the LCD-Display for 60 seconds.

Display Timeout:
The display turns off after 60 seconds of inactivity.

Hysteresis:
Turns on the device when the humidity is directly above the target value,
and off when it is 8% below.
*/
  
